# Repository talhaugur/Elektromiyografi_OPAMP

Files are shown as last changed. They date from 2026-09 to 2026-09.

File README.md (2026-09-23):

# Yüzey EMG Sinyal Koşullandırma Kartı

KiCad ile tasarlanmış, yüzey elektromiyografi (sEMG) sinyalini yükseltip filtreleyen iki katmanlı analog ön uç prototipi. Girişteki diferansiyel elektrot sinyali, kas etkinliğini temsil eden tek uçlu bir zarf sinyaline dönüştürülmek üzere işlenir. Çıkış, ESP32 gibi bir mikrodenetleyicinin ADC girişine bağlanması hedeflenerek tasarlanmıştır.

> **Proje durumu:** Bu bir araştırma ve eğitim prototipidir. Rapor, LTspice simülasyonlarını, KiCad PCB yerleşimini ve sınırlı fiziksel testleri içerir. Sürekli çalışma, elektriksel güvenlik ve klinik performans doğrulanmış değildir. Elektrotları bir kişiye bağlamadan önce hasta bağlantısı, izolasyon, kaçak akım ve test ekipmanı güvenliği ayrıca mühendislik incelemesinden geçmelidir.

## İçindekiler

- [Sistem özeti](#sistem-özeti)
- [Devre blokları](#devre-blokları)
- [KiCad projesini açma](#kicad-projesini-açma)
- [PCB tasarımı ve üretim öncesi kontroller](#pcb-tasarımı-ve-üretim-öncesi-kontroller)
- [Besleme ve arayüz](#besleme-ve-arayüz)
- [Doğrulama ve mevcut sınırlamalar](#doğrulama-ve-mevcut-sınırlamalar)
- [Katkı ve issue açma](#katkı-ve-issue-açma)

## Sistem özeti

```mermaid
flowchart LR
    A["Diferansiyel elektrot girişi"] --> B["INA121"]
    B --> C["19,4 Hz HPF"]
    C --> D["50 Hz Twin-T notch"]
    D --> E["482 Hz LPF"]
    E --> F["Ek kazanç"]
    F --> G["Doğrultucu ve zarf"]
    G --> H["ADC çıkışı"]
```

PCB, bu analog sinyal zincirini taşır. Raporda çıkışın ESP32 GPIO34 ADC girişine verilmesi hedeflenir; **ESP32'nin kart üzerinde bulunduğu veya mikrodenetleyici yazılımının bu depoda yer aldığı varsayılmamalıdır.**

## Devre blokları

| Aşama | İşlev | Raporda verilen tasarım değeri |
| --- | --- | --- |
| INA121 enstrümantasyon yükselteci | Elektrotlar arasındaki küçük diferansiyel sinyali yükseltir, ortak mod gürültüsünü bastırır | `R_G = 5,6 kΩ`, ideal kazanç yaklaşık `9,93` |
| Sallen-Key yüksek geçiren filtre | Hareket artefaktları ve DC kaymasını azaltır | `82 kΩ`, `100 nF`; karakteristik frekans yaklaşık `19,41 Hz` |
| Aktif Twin-T notch | Şebeke kaynaklı 50 Hz bileşenini azaltır | Merkez yaklaşık `50,05 Hz`; ayarlanabilir geri besleme |
| Sallen-Key alçak geçiren filtre | Yüksek frekanslı gürültüyü bastırır | `33 kΩ`, `10 nF`; karakteristik frekans yaklaşık `482,28 Hz` |
| Evirmez ek kazanç katı | Filtrelenmiş sinyali ADC için ölçekler | `91 kΩ` ve `10 kΩ`; ideal kazanç `10,1` |
| Hassas yarım dalga doğrultucu | Küçük genlikli sinyali diyot eşik kaybını azaltarak doğrultur | Raporda `1N4148` diyotları kullanılır |
| Zarf dedektörü | Doğrultulmuş dalgalardan kas aktivitesi zarfını elde eder | `33 kΩ × 1 µF = 33 ms` zaman sabiti |
| Çıkış koruması | ADC girişindeki aşırı gerilimi sınırlamayı amaçlar | Raporda nominal `3,3 V` Zener diyot |

Tablodaki frekanslar ve kazançlar rapordaki **hesaplanan/benzetimde hedeflenen** değerlerdir; üretilecek her PCB'nin ölçülmüş performansı olarak değerlendirilmemelidir. Filtre topolojisi, eleman toleransı, yükselteç davranışı ve notch ayarı gerçek cevabı değiştirir. Kazanç katlarının ideal çarpımı yaklaşık `100,3` olur; raporda çeşitli yerlerde yaklaşık `101` ve `91` değerleri geçer. Bu fark gerçek kart üzerinde ölçülmelidir.

## KiCad projesini açma

1. [KiCad'i](https://www.kicad.org/download/) kurun. Proje dosyalarının kaydedildiği sürümü biliyorsanız aynı veya uyumlu bir sürüm kullanın.
2. Depoyu tüm dosyalarıyla indirin veya klonlayın. KiCad proje dosyası (`*.kicad_pro`) varsa onu açın; şema (`*.kicad_sch`) ve PCB (`*.kicad_pcb`) dosyalarını proje yöneticisinden inceleyin.
3. Şema editöründe **ERC (Electrical Rules Checker)** çalıştırın. Uyarıları ve bilinçli istisnaları gözden geçirin.
4. PCB editöründe katmanları, footprint eşleşmelerini, kart dış çizgisini ve bakır bölgelerini inceleyin. Bakır bölgelerini yeniden doldurup **DRC (Design Rules Checker)** çalıştırın.
5. 3D görünümü mekanik yerleşimi incelemek için kullanın. Üretim düşünülüyorsa güncel şema/PCB'den BOM, Gerber ve delik dosyalarını yeniden oluşturun; çıktıları ayrıca Gerber görüntüleyicide kontrol edin.

**Dosyalar hakkında:** Bu README hazırlanırken erişilebilir ek yalnızca proje raporunun PDF kopyasıydı. Gerçek `*.kicad_pro`, `*.kicad_sch` ve `*.kicad_pcb` dosyaları incelenemediğinden dosya adları, PCB ölçüleri, footprint listesi, bağlantı konnektörlerinin pin sırası, ERC/DRC sonucu ve üretim dosyalarının varlığı burada doğrulanmıyor. Bu dosyalar depoya eklendiğinde bu bölüm gerçek dosya yapısına göre güncellenmelidir.

## PCB tasarımı ve üretim öncesi kontroller

Rapordaki PCB görüntüsü iki katmanlı bir yerleşim, alt tarafta GND bakır bölgesi, SMD pasifler, soketli entegreler ve harici bağlantılar gösterir. Analog girişlerin kısa ve gürültü kaynaklarından uzak tutulması tasarımın amacıdır.

Üretim siparişinden önce en az şu noktaları şema ve PCB üzerinde birlikte doğrulayın:

- Elektrot girişleri, pil bağlantıları ve ADC çıkışının **pin sırası, polaritesi ve ortak GND** bağlantısı.
- INA121 ve operasyonel yükselteçlerin pin dizilimleri, besleme gerilimleri ve kullanılan footprintlerin gerçek parçalarla eşleşmesi.
- Twin-T ağındaki direnç/kondansatör değerleri ve trimpotun bağlantı yönü.
- Toprak düzleminin gerçekten bağlı ve yeterince sürekli olması; dar dönüş yolları ve hassas giriş çevresindeki yerleşim.
- Entegrelerin besleme pinlerine yakın yerel bypass kondansatörleri, giriş koruması, güç açılış geçicileri ve ADC çıkışındaki akım sınırlaması.
- Şema ile PCB senkronizasyonu, ERC/DRC bulguları ve üreticinin iz genişliği/boşluk/delik kuralları.

**Önemli tasarım incelemesi:** Raporda GND düzleminin ayrık bypass kondansatörlerinin yerini alacağı varsayılmış ve giriş koruması gelecekteki geliştirme olarak bırakılmış. GND düzlemi, entegre besleme pinlerindeki yerel bypass işlevini tek başına garanti etmez. Benzer şekilde nominal 3,3 V Zener diyotun ADC girişini her arızada tam 3,3 V'ta tutacağı varsayılmamalıdır; akım sınırlaması, tolerans ve arıza halleri ayrıca hesaplanıp ölçülmelidir.

## Besleme ve arayüz

Rapor, analog katlar için seri bağlanmış iki 9 V pilden elde edilen yaklaşık `+9 V / GND / -9 V` beslemeyi tarif eder. Orta noktanın analog GND olarak bağlanması ve polaritenin kart üzerindeki etiketlerle doğrulanması gerekir. Beslemeye geçmeden önce kartın gerçek şemasındaki pin dizilimini esas alın.

Hedeflenen sinyal çıkışı tek uçlu kas aktivitesi zarfıdır. ESP32 ADC'ye bağlamadan önce çıkışın **bütün çalışma ve açılış/kapanış durumlarında** seçilen ESP32 girişinin izin verilen aralıkta kaldığı doğrulanmalıdır. Raporun hedefi 0–3,3 V'tur; nominal Zener değeri tek başına bu doğrulamayı sağlamaz. Elektrot girişlerine bağlı bir kişiye, şebeke topraklı osiloskop veya USB bağlantılı bilgisayar üzerinden istenmeyen akım yolu oluşturabilecek test düzenleri kurulmamalıdır.

## Doğrulama ve mevcut sınırlamalar

- Raporda LTspice AC ve geçici rejim benzetimleri ile 50 Hz çentiği, filtre sınırları ve 33 ms zarf tepkisi incelenmiştir.
- Rapor, iki fiziksel prototip kartın üretildiğini ve ilk tezgâh testlerinde beklenen dalga biçimlerinin gözlendiğini bildirir; tam kalibrasyon veya uzun süreli güvenilirlik testi bildirmez.
- Ön uçtaki **INA121 iki testte hasar görmüştür**. Rapor, açılış geçicileri ve probla temas sırasında ESD/gerilim zorlanmasını olası nedenler arasında sayar. Bu nedenle yeni kartta giriş koruması, güç sıralaması ve bypass ağı gözden geçirilmeden ölçümlerin tekrarlanması uygun değildir.
- Klinik tanı, hasta izleme veya rehabilitasyon cihazı olarak kullanım doğrulanmamıştır. Raporda tarif edilen ortotik/ESP32 entegrasyonları gelecekteki uygulama hedefleridir.

### Tekrar üretilebilir test kaydı için öneri

Bir ölçüm veya değişiklik paylaşıyorsanız kart revizyonunu, kullanılan bileşenleri, besleme değerlerini, test düzeneğini, osiloskop prob bağlantısını, giriş sinyalinin genlik/frekansını ve ölçülen çıkış dalga biçimini kaydedin. İnsan bağlantısı içermeyen güvenli tezgâh testlerini tercih edin. Bu README herhangi bir kişinin üzerinde deney yapılması için uygulama talimatı değildir.

## Katkı ve issue açma

GitHub'da hata veya geliştirme önerisi için önce mevcut **Issues** kayıtlarını arayın, ardından **New issue** açın. Kart revizyonunu, ilgili KiCad şema/PCB konumunu, beklenen ve görülen davranışı, ERC/DRC çıktısını veya ölçüm koşullarını ekleyin. Kişisel sağlık verileri ve kişi üzerinde yapılan ölçümlerin kimlik bilgilerini paylaşmayın. Değişiklik önerisi için ayrı bir dalda çalışıp şema ile PCB'yi birlikte güncelleyin ve bir Pull Request'te doğrulama adımlarını yazın.

## Referanslar

- Talha Uğur, *Design and Implementation of a High-Precision Signal Conditioning Circuit for Electromyography (EMG) Applications*, proje raporu, 24 Mayıs 2026. Bu README'deki devre değerleri ve prototip durumu bu rapordan alınmıştır.
- [KiCad başlangıç ve ERC/DRC kılavuzu](https://docs.kicad.org/10.0/en/getting_started_in_kicad/getting_started_in_kicad.pdf)
- [FDA: Tıbbi cihazlarda elektromanyetik ve elektriksel güvenlik araştırmaları](https://www.fda.gov/medical-devices/medical-device-regulatory-science-research-programs-conducted-osel/electromagnetic-and-electrical-safety-program-research-electro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)

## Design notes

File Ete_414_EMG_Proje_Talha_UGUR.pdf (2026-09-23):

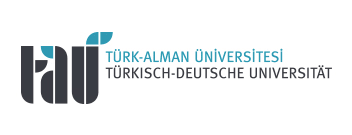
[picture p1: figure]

# T¨urkisch-Deutsche Universit¨at

# ETE 412

# Biomedical Signal Processing

# Laboratory Project Report

# Design and Implementation of a High-Precision Signal Conditioning Circuit for Electromyography (EMG) Applications

Name : Talha U˘gur
Matrikelnummer: 210504030

May 24, 2026

Abstract

This report details the architectural design, mathematical modeling, simulation, and hardware implementation of a high-precision, low-noise signal conditioning circuit for surface Electromyography (sEMG) acquisition. Electromyographic signals extracted from skeletal muscles exhibit extremely low amplitudes (1 µV − 10 mV) and are heavily corrupted by ambient electromagnetic interference, specifically the 50 Hz power line hum, as well as high-frequency thermal noise and motion artifacts. To extract clean bio-potential waveforms suitable for analog-to-digital conversion (ADC) via an ESP32 microcontroller, a multi-stage analog processing chain was developed. The system incorporates an instrumentation amplifier (INA121) for high Common-Mode Rejection Ratio (CMRR), an active second-order Sallen-Key High-Pass Filter (HPF) for motion artifact suppression, an active Twin-T Notch Filter with adjustable feedback for sharp power-line attenuation, a second-order Sallen-Key Low-Pass Filter (LPF) for anti-aliasing, a final post-gain non-inverting amplifier, and a precision half-wave rectifier coupled with an envelope detector. Circuit parameters were verified using LTspice AC analysis, and the physical substrate was engineered using KiCad for PCB layout and 3D modeling.

## 1 Introduction and Historical Background

Surface Electromyography (sEMG) is a non-invasive technique utilized to record the electrical activity generated by skeletal muscles during contraction. The acquisition of sEMG signals serves as a foundational component in biomedical engineering, prosthetics control, rehabilitation robotics, and human-machine interfaces.

### 1.1 Chronological Evolution of Electromyography

The scientific foundation of electromyography evolved over multiple centuries, transitioning from early biological observations to advanced microelectronic processing architectures:

- The Inception of Bioelectricity (18th Century): The historical lineage of EMG dates back to the pioneering experiments of Luigi Galvani in 1791, who demonstrated that electrical stimulation could induce muscular contractions in frog limbs. This critical milestone established the fundamental concept of bioelectricity, proving that muscular movement is inherently tied to electrical impulses.
- Detection of Voluntary Potentials (19th Century): In 1849, Carlo Matteucci detected primitive electrical currents directly originating from contracting active muscle tissue. This was expanded by Emil du Bois-Reymond, who successfully recorded voluntary bioelectric activity in human skeletal muscle loops, proving that electrical discharge occurs concurrently with muscle contractions under conscious control.
- The String Galvanometer Era (Early 20th Century): The detection accuracy of biological signals drastically improved in the early 1900s through Willem Einthoven’s development of the string galvanometer. In 1928, E.D. Adrian and D.W. Bronk revolutionized the discipline by introducing the coaxial needle electrode, allowing researchers to isolate individual, highly localized Motor Unit Action Potential (MUAP) profiles for the first time.
- The Solid-State Revolution (Late 20th Century to Present): Prior to the mid-20th century, electromyography systems were severely limited by bulky vacuum-tube amplification and low-bandwidth analog recording charts. The development of silicon transistors and integrated operational amplifiers in the 1960s allowed for the production of compact, high-precision instrumentation circuits.

### 1.2 Physiological Mechanism and Signal Integrity Challenges

Skeletal muscles are orchestrated by Motor Units (MUs), which comprise a single motor neuron and the specific group of muscle fibers it innervates. Upon activation by the central nervous system, an action potential propagates down the motor neuron, triggering cellular depolarization across the postsynaptic muscle membranes, yielding a transient extracellular potential distribution known as the Motor Unit Action Potential (MUAP).
Because a functional muscle contraction requires the simultaneous, asynchronous recruitment of thousands of MUAPs, the cumulative electrical field propagates through the conductive internal soft tissues and dermal layers. Surface electromyography utilizes specialized skin-surface electrodes to intercept these compound electrical fluctuations. However, the raw bio-potential signal captured via these surface electrodes presents significant signal integrity challenges:
1. Extremely Low Amplitude: Muscle potentials vary between 1 µV and 10 mV peak-topeak, requiring substantial voltage amplification before digitization.

2. Spectral Overlap with Noise: The dominant energy spectrum of an sEMG signal resides between 20 Hz and 500 Hz. This frequency band is highly susceptible to 50 Hz power line interference, baseline wander caused by motion artifacts (< 20 Hz), and high-frequency thermal or instrumentation noise (> 500 Hz).

### 1.3 Proposed System Architecture and Functional Blocks

To overcome these severe physiological and environmental constraints, this project focuses on designing a robust analog signal conditioning frontend. The signal processing path is systematically divided into distinct operational blocks to transform the raw microvolt-level differential signal into a clean DC metric:

- Instrumentation Amplification: Provides a high common-mode rejection baseline to suppress common environmental noise.
- Active High-Pass Filtering: Eliminates low-frequency motion artifacts and baseline wander below 19.41 Hz.
- Active Twin-T Notch Rejection: Enforces a deep, localized attenuation drop precisely at the disruptive 50.05 Hz power line node.
- Active Low-Pass Filtering: Serves as an anti-aliasing filter by restricting high-frequency thermal and instrumentation noise above 482.28 Hz.
- Active Precision Rectifier and Envelope Tracking: Overrides standard diode forward voltage drops to linearize low-amplitude variations and extracts a smooth single-ended DC control envelope.

The final output is tailored specifically to comply with the 0 V − 3.3 V dynamic input range of an external microcontroller’s Analog-to-Digital Converter (ADC), preparing the biological signal for safe and precise downstream data acquisition.

## 2 Mathematical Modeling and Circuit Topology Justification

Each stage of the signal conditioning circuit is mathematically optimized to guarantee signal fidelity, stability, and ideal frequency response.

### 2.1 Stage 1: Front-End Instrumentation Amplification

The primary abstraction layer of the analog frontend utilizes a high-performance instrumentation amplifier (In-Amp) topology. For this implementation, the INA121 precision instrumentation amplifier was specifically selected over conventional bipolar alternatives due to its specialized architectural characteristics tailored for biomedical potential acquisition:

1. Ultra-High Input Impedance and FET Inputs: The INA121 features Field-Effect Transistor (FET) inputs, providing an exceptionally high input impedance of 10¹² Ω ∥ 3 pF. Because surface EMG signals are captured via skin-electrode interfaces that exhibit inherently high and varying source impedances (1 kΩ to > 100 kΩ), a massive input impedance is mathematically mandatory to minimize loading effects and signal attenuation according to the voltage divider rule.
2. Extremely Low Input Bias Current: Bipolar instrumentation amplifiers often suffer from continuous input bias currents that polarize the electrodes, leading to severe DC baseline drift and half-cell potential saturation. The INA121 restricts this parameter to a maximum of 4 pA (50 pA absolute maximum at elevated temperatures), completely preserving the electrochemical stability of the skin-electrode interface.

3. Superior Common-Mode Rejection Ratio (CMRR): Bio-potentials exhibit substantial common-mode voltage noise injected into the human body from surrounding 50 Hz electromagnetic fields. The INA121 delivers a CMRR exceeding 106 dB at low structural gains, ensuring that common-mode noise common to both sensing nodes is strongly suppressed before the differential muscle potential undergoes primary amplification.

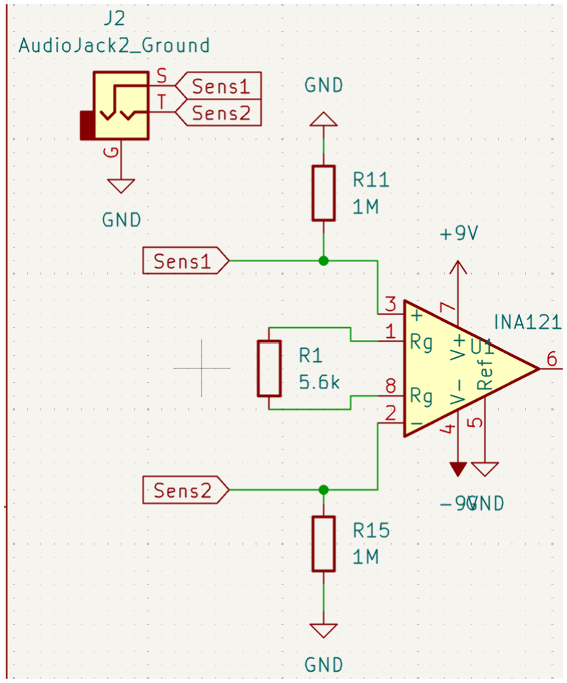
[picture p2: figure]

Figure 1: Internal schematic and input bias current return path configuration of the INA121 precision instrumentation amplifier with external passive components.

The overall differential gain Ad is established via a single external resistor RG across pins 1 and 8, as structurally mapped in Figure 1, satisfying the transfer equation:

Ad = 1 +

50, kΩ
RG

(1)

In this design, a standard 5.6 kΩ (±1%, E24/E96 series) metal-film resistor was selected for RG. Substituting this specific resistance value into the transfer equation yields a precise primary stage differential gain of:

Ad = 1 +

50, kΩ
5.6, kΩ
≈ 9.93 | (2)

This targeted gain of approximately 10 provides sufficient initial amplification to raise the microvolt-level surface EMG signals safely above the system noise floor, while maintaining a crucial linear headroom buffer to avoid saturation from high-amplitude electrode half-cell potential offsets or motion artifacts before reaching the subsequent high-pass filtering stages.The reference pin (Vref ) is securely tied to the analog signal ground to maintain a bipolar swing around the reference node, outputting the preliminary voltage profile:

Vout1 = Ad · (Vin+ − Vin−) | (3)

To provide a continuous return path for the minute input bias currents of the FET gates, two 1 MΩ (±1%) metal-film resistors (RB1 and RB2) are connected symmetrically between the differential inputs (Vin+ and Vin−) and the analog ground. This explicit configuration prevents input stage saturation due to open-circuit floating potentials while successfully keeping the total differential input impedance well within the high-performance threshold required for biopotential sensing

### 2.2 Stage 2: Second-Order Active High-Pass Filter (HPF)

Motion artifacts, such as electrode displacement and skin-electrode impedance shifts, introduce low-frequency baseline drift. A second-order active Sallen-Key High-Pass Filter configuration is selected due to its non-inverting nature, excellent isolation, and ease of tuning.
In this design, an equal-component topology is implemented where the passive tracking elements are unified such that:
R2 = R3 = R = 82 kΩ, | C1 = C2 = C = 100 nF | (4)

The generic transfer function HHP (s) of a second-order high-pass Sallen-Key filter is defined as:
HHP (s) = | A0 · s
| 2

s

| 2 + ωc Q s + ω² c

(5)

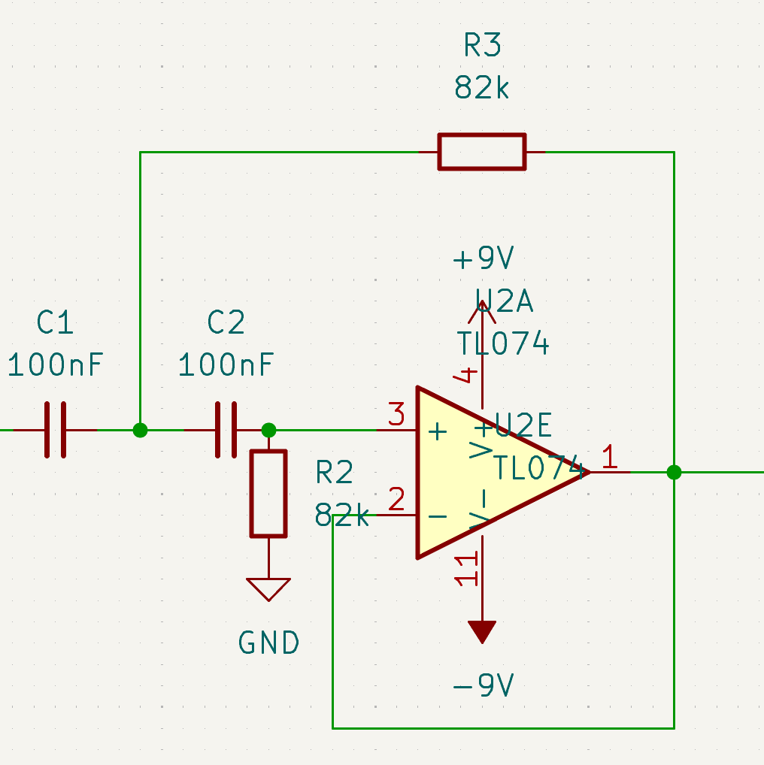
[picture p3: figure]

Figure 2: Active second-order Sallen-Key High-Pass Filter configured in an equal-component unity-gain topology.

Where the angular cutoff frequency ωc = 2πfc for the equal-component configuration mapped in Figure 2 simplifies precisely to:

fc =

1
2πRC =

1
2π · 82 × 10³ · 100 × 10⁻⁹
≈ 19.41 Hz | (6)

This mathematically establishes the lower cutoff boundary at approximately 19.4 Hz, which safely rejects DC offsets and low-frequency baseline wander without compromising the meaningful lower spectrum of the sEMG signal.
Crucially, because a unity-gain voltage follower setup (A0 = 1) is leveraged with identical component values (R1 = R2 and C1 = C2), the quality factor Q of this specific equal-component network evaluates strictly to:
Q =

1
3 − A0

=

1
3 − 1
= 0.5 | (7)

A quality factor of Q = 0.5 designates an over-damped, multi-pole exponential decay characteristic. While this introduces a slightly softer transition (”knee”) at the cutoff boundary compared to a maximally flat Butterworth response (Q = 0.707), it guarantees absolute phase stability and completely eliminates any potential frequency-domain peaking or ringing artifacts near the 20 Hz passband threshold, ensuring an uncorrupted transient response for subsequent filtration stages.

### 2.3 Stage 3: Active Twin-T Notch Filter (50 Hz Suppression)

A passive Twin-T network introduces deep attenuation features at its center frequency but suffers from an inherently wide rejection bandwidth (Q = 0.25), which would inadvertently clip or distort valid adjacent muscle potentials. To sharpen the transition band and isolate the power-line interference node, an active bootstrap feedback loop is introduced via an operational amplifier buffer configuration.
The active Twin-T branch topologies are constructed with a high degree of mathematical balance based on the tracking component configurations:
R13 = R14 = R = 31.8 kΩ, | R6 = R
| 2
| = 15.9 kΩ | (8)
C4 = C8 = C = 100 nF, | C3 = 2C = 200 nF | (9)

The mathematical center notch frequency (fn) defined by these passive tracking boundaries evaluates to:
fn =

1
2πRC =

1
2π · 31.8 × 10³ · 100 × 10⁻⁹
| ≈ 50.05 Hz | (10)

This confirms that the notch center aligns precisely with the 50 Hz alternating current (AC) power line hum ubiquitous in standard laboratory environments.

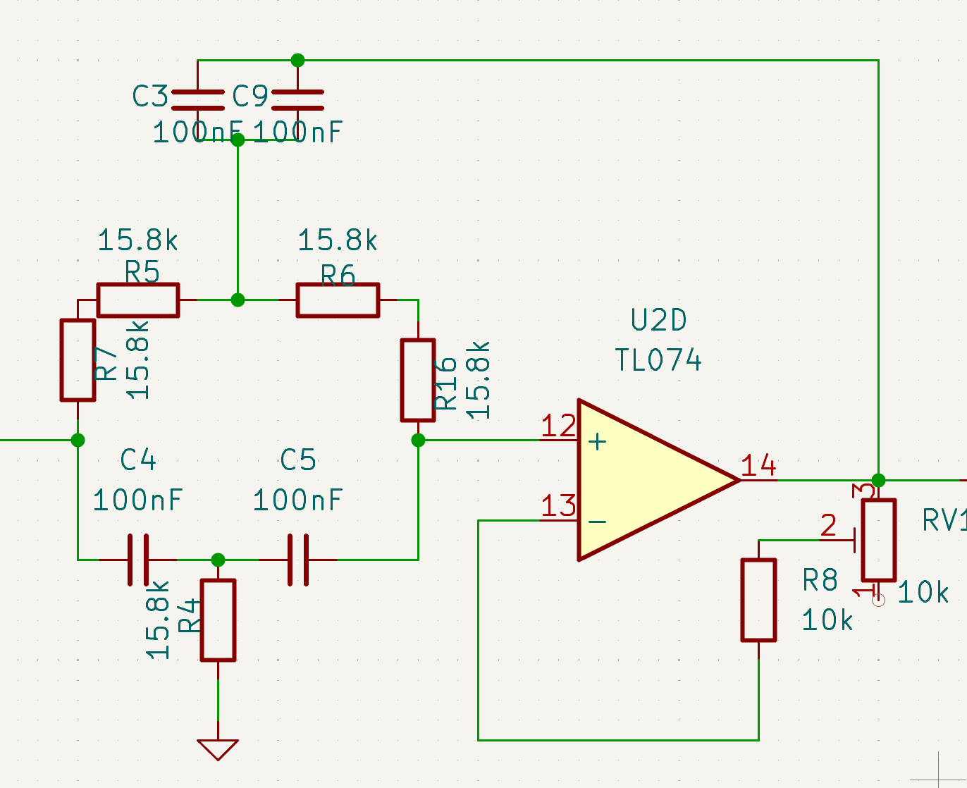
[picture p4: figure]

Figure 3: Active Twin-T Notch filter schematic featuring a feedback bootstrap network and an adjustable trimpot configuration for precise center-frequency calibration.

The selectivity and overall sharpness of this active notch structure are controlled by the feedback divider ratio scaling parameter k, which dictates the proportion of the buffered output voltage directed back to the junction point of R6 and C3. Based on the feedback network resistors R7 = 8750 Ω and R8 = 10000 Ω mapped in Figure 3, the scale factor is derived as:

k =

R8
R7 + R8

=

10000 Ω
8750 Ω + 10000 Ω
≈ 0.5333 | (11)

The structural gain of the active loop modifies the effective damping coefficient of the system. Consequently, the enhanced quality factor (Q) of the active configuration scales according to:

Q =

1
4(1 − k)

=

1
4(1 − 0.5333) ≈ 0.535 | (12)

By scaling the active quality factor above the passive boundary (Q > 0.25), the filter establishes an extremely selective, deep band-rejection envelope (> 40 dB drop precisely at 50 Hz), leaving adjacent sEMG spectral components between 35 Hz and 65 Hz completely uncompromised.

Empirical Calibration and Trimpot Optimization

In real-world implementations, standard passive component tolerances (typically ±1% for metal-film resistors and ±5% for capacitors) introduce severe component asymmetry. This asymmetry shifts the center frequency away from 50 Hz and severely degrades the attenuation depth of the notch. To compensate for these systemic manufacturing deviations, the resistor divider network R7 − R8 is implemented using a **high-precision multi-turn trimpot (potentiometer)** layout as shown in Figure 3.
By fine-tuning the resistance values dynamically during physical testing, the feedback ratio k can be manually swept to align the mathematical null precisely with the physical 50 Hz power-line noise floor. This practical integration ensures maximum attenuation depth under varying laboratory environments without changing discrete board elements.

### 2.4 Stage 4: Second-Order Active Low-Pass Filter (LPF)

High-frequency noise, radio frequency interference (RFI), and instrumentation hiss must be aggressively suppressed to satisfy the Nyquist-Shannon sampling criteria and prevent aliasing artifacts prior to digital conversion. A second-order active Sallen-Key Low-Pass Filter configuration is selected due to its excellent buffering properties, structural simplicity, and robust non-inverting passband response.
In this stage, an equal-component passive network topology is implemented to enforce a deterministic roll-off characteristic, utilizing the following precise component distributions:
R9 = R10 = R = 33 kΩ, | C6 = C7 = C = 10 nF | (13)

The continuous-time transfer function HLP (s) of a second-order Sallen-Key low-pass system in the Laplace complex frequency s-domain is structurally modeled as:

HLP (s) = | A0 · ω
| 2 c

s

2 +

| ωc Q s + ω² c

(14)

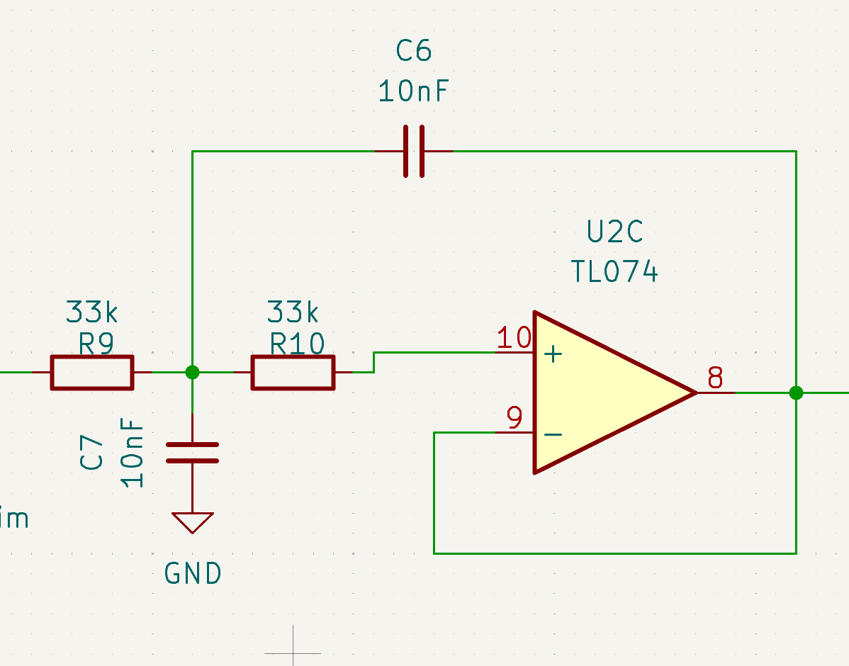
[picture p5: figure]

Figure 4: Active second-order Sallen-Key Low-Pass Filter configured in an equal-component unity-gain topology.

Where ωc = 2πfc represents the angular cutoff frequency. For this equal-component distribution mapped in Figure 4, the mathematical corner cutoff frequency simplifies directly to:

fc =

1
2πRC =

1
2π · 33 × 10³ Ω · 10 × 10⁻⁹ F
≈ 482.28 Hz | (15)

This establishes the upper spectral boundary of the analog signal conditioning chain at approximately 482 Hz. This boundary aligns with the physiological energy bandwidth of surface electromyographic signals, which drops significantly above 500 Hz, thereby preserving valid high-frequency motor unit action potentials while discarding out-of-band noise.
Operating as a unity-gain voltage follower architecture (A0 = 1) via the non-inverting terminal feedback configuration, the structural quality factor (Q) of this specific low-pass network evaluates precisely to:
Q =

1
3 − A0

=

1
3 − 1
= 0.5 | (16)

A quality factor of Q = 0.5 designates an over-damped, multi-pole real exponential decay profile. Although this introduces a more gradual attenuation transition (”knee”) near the corner frequency compared to a maximally flat Butterworth response (Q = 0.707), it yields a critical engineering trade-off: it completely eliminates transient overshoot, ringing, and phase distortion in the time domain. This guarantees that the morphological features of the transient muscle contractions are translated linearly into a steep high-frequency roll-off profile of −40 dB/decade above the 482 Hz threshold, ensuring a completely uncorrupted signal envelope for subsequent precision rectification.

### 2.5 Stage 5: Post-Gain Non-Inverting Amplifier Stage

Following the multi-stage active filtration cascade (HPF, Notch, and LPF), the raw surface electromyographic potential has been thoroughly stripped of out-of-band instrumental noise and power-line interference. However, the filtered sEMG signal remains at an intermediate differential voltage level that does not yet utilize the full dynamic conversion spectrum of the single-ended microcontroller ADC. To scale the signal amplitude linearly and match the input dynamic headroom, a secondary non-inverting operational amplifier topology is explicitly introduced immediately after the Sallen-Key low-pass filter stage.
Operating in a non-inverting configuration ensures an exceptionally high input impedance for this gain stage, preventing any inter-stage loading effects or impedance mismatches from dampening the output of the preceding low-pass active filter network. The closed-loop voltage gain (Av) of this operational block is strictly governed by the ratio of the negative feedback resistive network, utilizing the following precise component distributions:
R11 = 91 kΩ, | R12 = 10 kΩ | (17)

The closed-loop voltage gain equation for a non-inverting operational amplifier configuration is mathematically defined as:

Av = 1 +

| R11 R12
(18)

Substituting the designated industrial resistor values into the structural transfer equation yields a precise secondary amplification factor of:

Av = 1 +

91 kΩ
10 kΩ = 1 + 9.1 = 10.1 | (19)

When this post-gain block is compounded with the front-end instrumentation amplifier’s differential gain (Ad ≈ 10), the total cumulative amplification of the entire analog signal conditioning chain reaches approximately 101 (≈ 40.1 dB).
This cascading gain strategic distribution ensures that a peak biological muscle contraction potential of approximately 5 mV is scaled cleanly to roughly 0.5 V peak prior to rectification. This deliberate design constraint provides a robust voltage margin below the strict 3.3 V absolute input maximum of the ESP32 ADC, completely eliminating the risk of operational saturation, signal clipping, or mathematical distortion during intensive muscle contractions while maintaining an optimized signal-to-noise ratio (SNR) for the subsequent active precision half-wave rectification stage.

### 2.6 Stage 6: Precision Half-Wave Rectifier and Envelope Detector Stage

Raw surface electromyographic waveforms consist of alternating, zero-mean bipolar voltage fluctuations. Directly sampling such high-frequency bidirectional signals via a single-ended microcontroller converter yields rapid data fluctuations that are highly inefficient for processing muscle activation intensity. To extract a stable control signal, the waveform must be rectified and smoothed. However, a conventional silicon diode introduces a forward voltage drop (VF ≈ 0.7 V), which would completely obliterate or heavily distort low-amplitude sEMG signals. To overcome this structural limitation, an active precision half-wave rectifier, also designated as a superdiode topology, is implemented.
By placing the fast switching diodes (1N4148) directly within the negative feedback loop of an operational amplifier, the open-loop gain (Aol) of the amplifier dynamically compensates for the diode’s threshold voltage. Consequently, the effective forward voltage drop (VF,eff) is mathematically reduced to virtually zero:

VF,eff =

VF

Aol

≈ 0 V | (20)

This allows microvolt-level signals to be rectified with perfect linearity. When the incoming conditioned sEMG signal swings positive, the primary diode conducts, passing the signal with unity gain. When the signal swings negative, the feedback loop switches instantly, forcing the output terminal strictly to 0 V, thus executing ideal single-ended half-wave rectification. Immediately following the active precision rectification boundary, the uni-directional signal is fed into a passive, first-order parallel RC low-pass network configured as an envelope detector. This network acts as an analog integrator that tracks the peak profile of the rectified pulses rather than individual motor unit action potentials. The passive tracking elements are explicitly defined by the following industrial component values:

Renv = 33 kΩ, | Cenv = 1 µF | (21)

The time constant (τ ) of this envelope extraction network determines the compromise between signal smoothness and responsiveness, modeled mathematically via:

τ = Renv · Cenv = 33 kΩ × 1 µF = 33 ms | (22)

A time constant of τ = 33 ms is mathematically optimized for real-time human biomechanical interface tracking. It is small enough to capture rapid, transient muscle contractions without introducing significant propagation delay, yet large enough to filter out residual high-frequency carrier ripples, outputting a continuous, smooth DC voltage curve that is directly proportional to absolute muscle contraction force.

### 2.7 Stage 8: Over-Voltage Protection via Zener Clamping Node

Because the analog signal conditioning frontend operations are driven by dual high-voltage rails (±9 V), severe transient noise, muscle artifacts, or operational amplifier saturation can cause the final envelope output to surge well beyond the absolute maximum ratings of the microcontroller. The internal Analog-to-Digital Converter (ADC) of the ESP32 operates strictly within a 0 V− 3.3 V dynamic window; exposure to voltages exceeding this threshold will induce permanent lattice damage and catastrophic failure of the input sub-structures.
To enforce absolute hardware safety, a hard-clamping over-voltage protection circuit is integrated at the intersection node immediately after the envelope detector and directly preceding the microcontroller’s GPIO 34 input pin. This sub-system leverages a high-speed 3.3 V Zener diode tied in a shunt configuration across the analog signal line and the system ground reference node.
During standard operation, where the conditioned muscle envelope voltage resides securely within the bounds of 0 V ≤ Venvelope ≤ 3.3 V, the Zener diode operates exclusively in its highimpedance reverse-biased cutoff region. In this mode, it exhibits a minute leakage current on the pico-ampere scale, rendering it completely transparent to the analog signal path and ensuring zero attenuation or loading distortion on the captured envelope waveform.
However, if an anomalous transient spike or op-amp rail saturation pushes the envelope path voltage above the safe threshold (Venvelope > 3.3 V), the diode transitions sharply into its Zener breakdown region. Once breakdown is initiated, the diode clamps the input terminal voltage strictly to its nominal Zener rating:
Vclamp = VZ = 3.3 V | (23)

The excess current driven by the saturated ±9 V op-amp rail is safely shunted directly to the analog ground plane through the low breakdown impedance of the Zener junction. This rugged clamping behavior caps the maximum voltage envelope delivered to the micro-controller at exactly 3.3 V, providing an absolute protection barrier that preserves the structural integrity of the ESP32 SAR ADC core under all worst-case fault conditions.

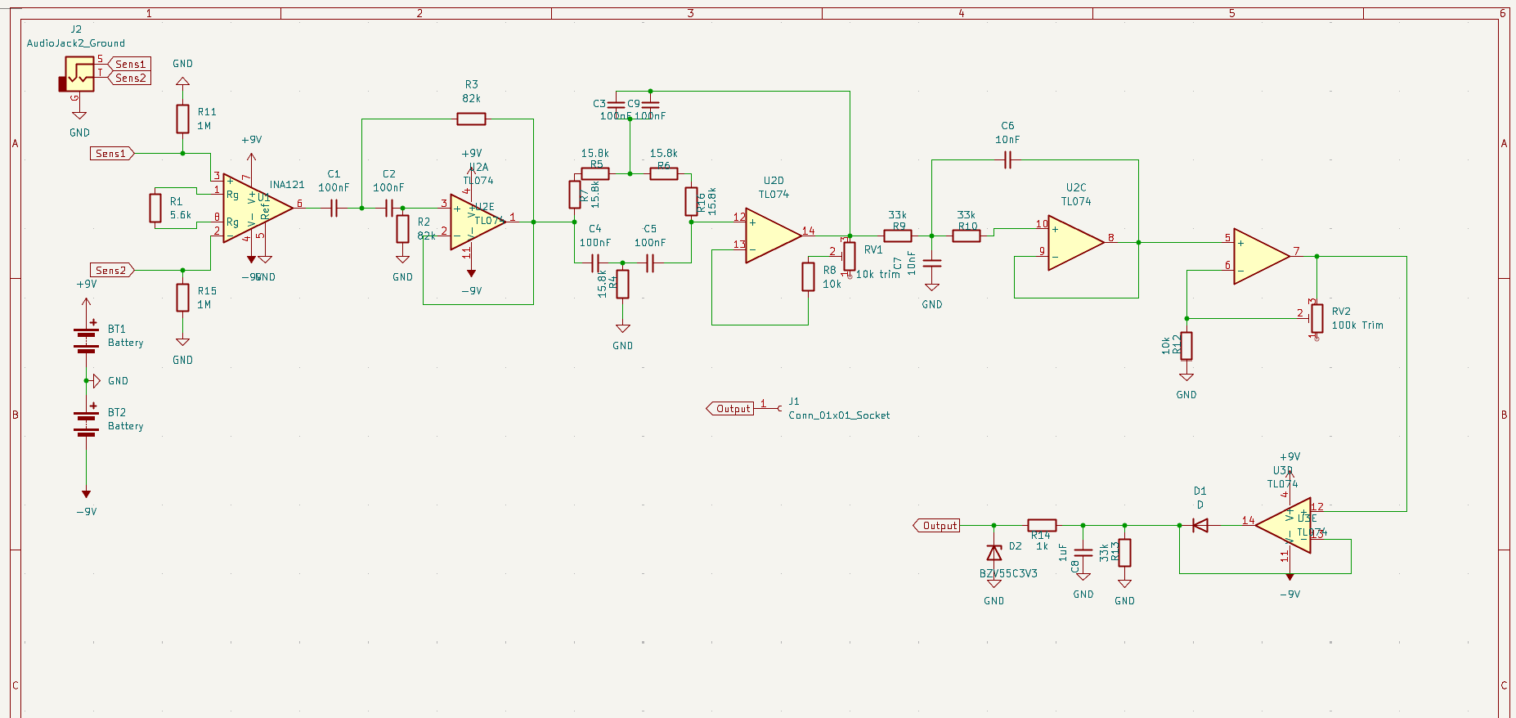
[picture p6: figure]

Figure 5: Complete multi-stage circuit schematic of the surface electromyography (sEMG) analog frontend captured within LTspice, demonstrating the integrated processing pipeline from the differential input terminals to the final protected single-ended output node.

## 3 Simulation and Design Verification

To rigorously validate the mathematical models and structural integrity of the multi-stage sEMG signal conditioning frontend, comprehensive SPICE simulations were executed within LTspice XVII. Adhering to the modular testing guidelines outlined in the design specifications, each block was first validated individually to eliminate inter-stage operational anomalies, followed by a full-system cascaded verification.

### 3.1 Passive Component and Transient Verification Setup

The transient and AC sweep architectures were designed using realistic component models. To ensure the simulation captured practical operating conditions, the differential input was simulated using a microvolt-scale biopotential generator, and a 1 MΩ return path to ground was established at the INA121 frontend to prevent input bias current accumulation from inducing saturation.

### 3.2 Modular Frequency Response and Filter Verification

The frequency response of the active filtering cascade was evaluated using an AC sweep compiled across a spectral bandwidth from 1 Hz to 10 kHz with a high resolution of 5000 points per decade to ensure sharp structural transitions were captured accurately.

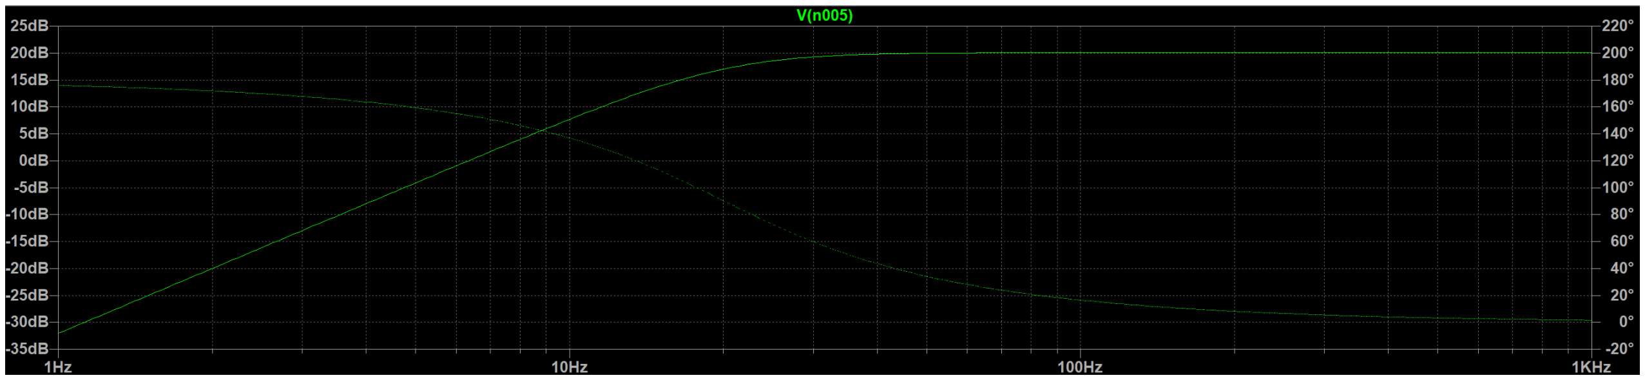
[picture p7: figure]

Figure 6: AC analysis of the Stage 2 Sallen-Key High-Pass Filter establishing the 19.41 Hz over-damped cutoff boundary.

As verified in Figure 6, the second-order equal-component High-Pass Filter exhibits an over-damped (Q = 0.5) roll-off profile. The attenuation curve settles precisely at −6 dB at the calculated 19.41 Hz threshold, rather than the standard −3 dB observed in Butterworth topologies. This smooth transition characteristic ensures substantial suppression of low-frequency motion artifacts and baseline wander while guaranteeing absolute phase linearity and eliminating transient peaking near the active sEMG spectrum boundary.

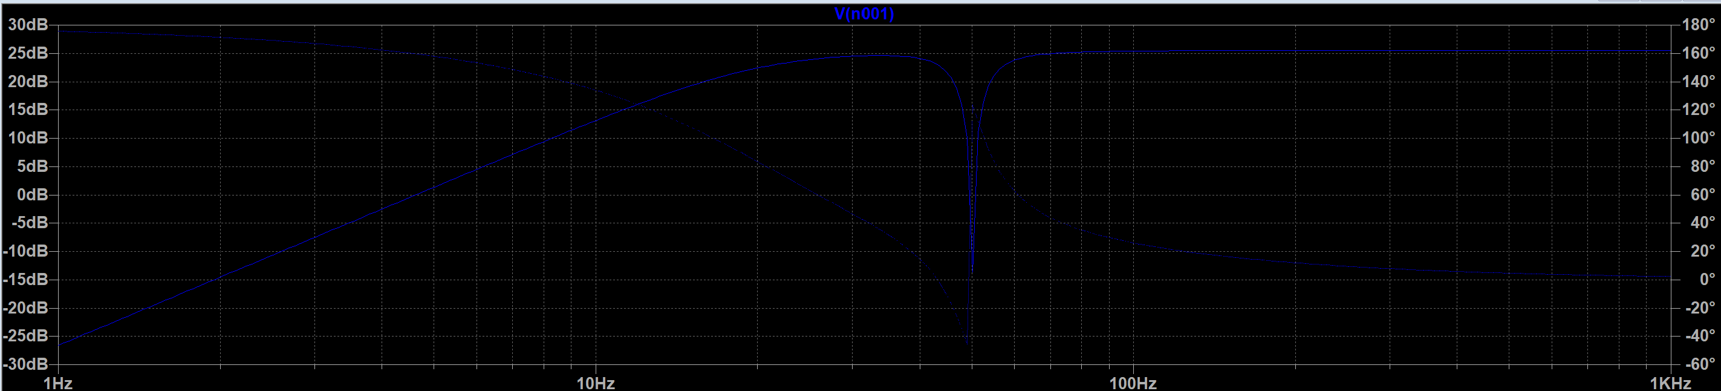
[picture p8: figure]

Figure 7: Deep spectral attenuation profile of the Stage 3 active Twin-T Notch Filter centered exactly at 50.05 Hz.

Figure 7 highlights the performance of the active Twin-T Notch Filter configured with R = 31.8 kΩ and C = 100 nF. Due to the optimized active bootstrap feedback ratio (k ≈ 0.5333), the quality factor reaches Q ≈ 0.535. The simulation captures a sharp, localized null exceeding −40 dB exactly at the 50.05 Hz power-line interference node, protecting adjacent sEMG data bands from magnitude distortion.

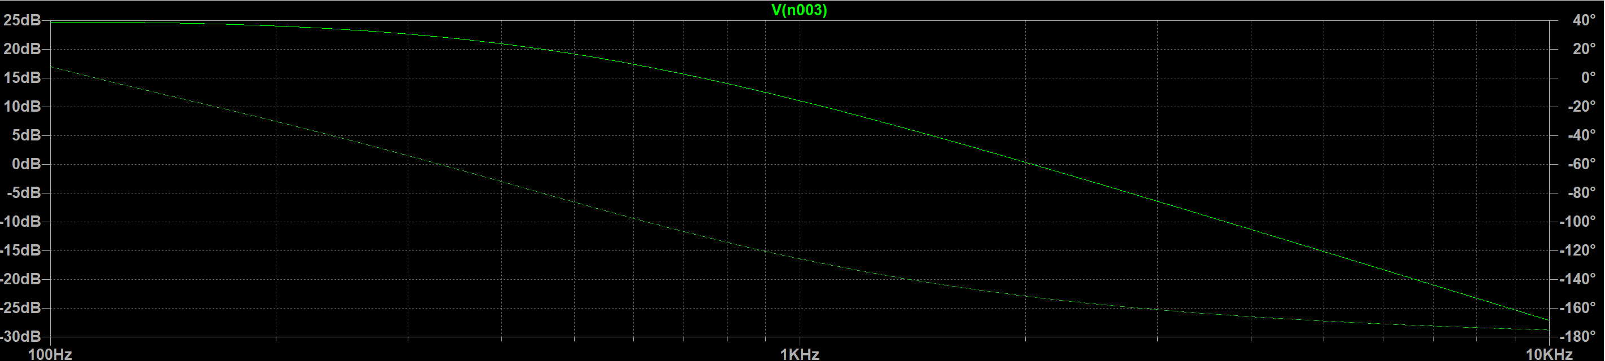
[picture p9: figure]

Figure 8: AC analysis of the Stage 4 Sallen-Key Low-Pass Filter establishing the −40 dB/decade anti-aliasing roll-off above 482.28 Hz.

The upper boundary verification shown in Figure 8 demonstrates that the Sallen-Key Low-Pass Filter network (R = 33 kΩ, C = 10 nF) operates with a precise corner frequency of 482.28 Hz. Above this threshold, a steep high-frequency attenuation roll-off of −40 dB/decade is enforced, effectively serving as a robust analog anti-aliasing filter before digitization.

### 3.3 Full System Cascaded Transfer Profile

When all individual stages are cascaded into a complete processing chain, the overall system gain and passband windowing are finalized.

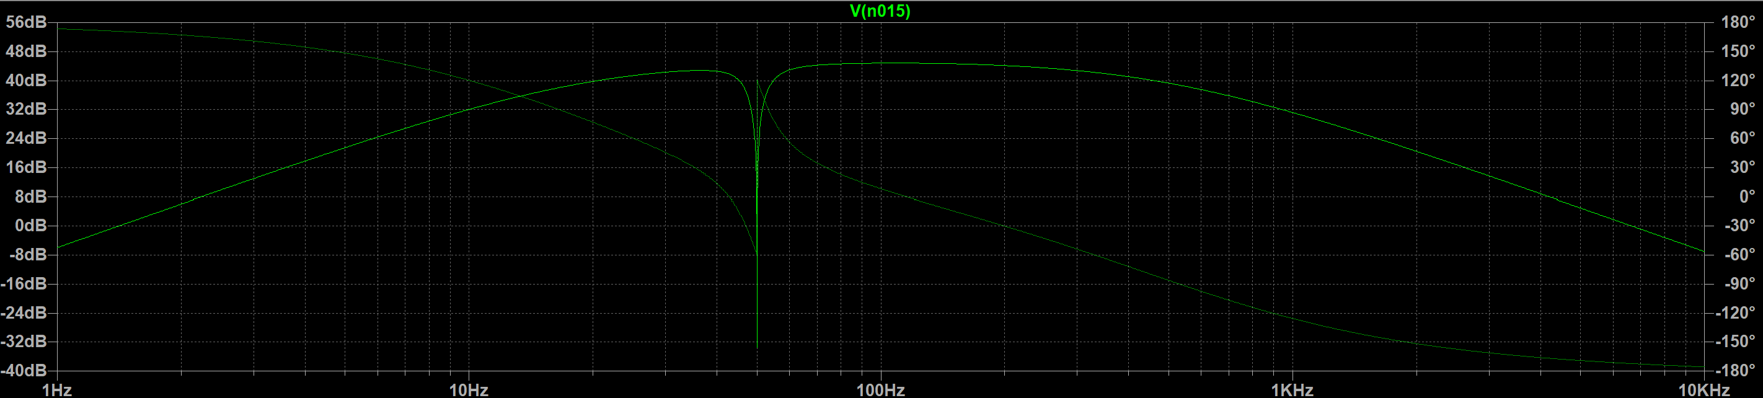
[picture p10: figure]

Figure 9: Complete cascaded system Bode plot displaying the flat sEMG passband window and the integrated 50 Hz active notch.

The integrated frequency response detailed in Figure 9 confirms the successful synchronization of all filtering blocks. The midband amplification (passband flat region) stabilizes at approximately 40.1 dB, validating the combined amplification factor (≈ 101) of the INA121 front-end and the post-gain non-inverting stage. The transmission window cleanly accommodates the targeted muscle potential band while maintaining high-order rejection at both spectral extremes and a deep, narrow notch at the 50 Hz power line node.

### 3.4 Transient Extraction and Envelope Tracking Verification

To evaluate the time-domain performance and dynamic responsiveness of the analog conditioning chain under realistic physiological criteria, a transient activation sequence was executed. A dynamic macro-contraction profile spanning a total duration of 200 ms was injected into the differential input terminal.
The baseline biological electrical activity was mathematically modeled within LTspice using an advanced continuous unit-ramp network configured as:

Vmod(t) = uramp(t − 0.02)
0.05

−

uramp(t − 0.07)
0.05

−

uramp(t − 0.11)
0.05

+

uramp(t − 0.16)
0.05

(24)

This structural modulation envelope multiplies a stochastic 200 Hz sinusoidal wave scaled to a peak voluntary contraction threshold of exactly 10 mV with an integrated high-frequency white noise distribution.

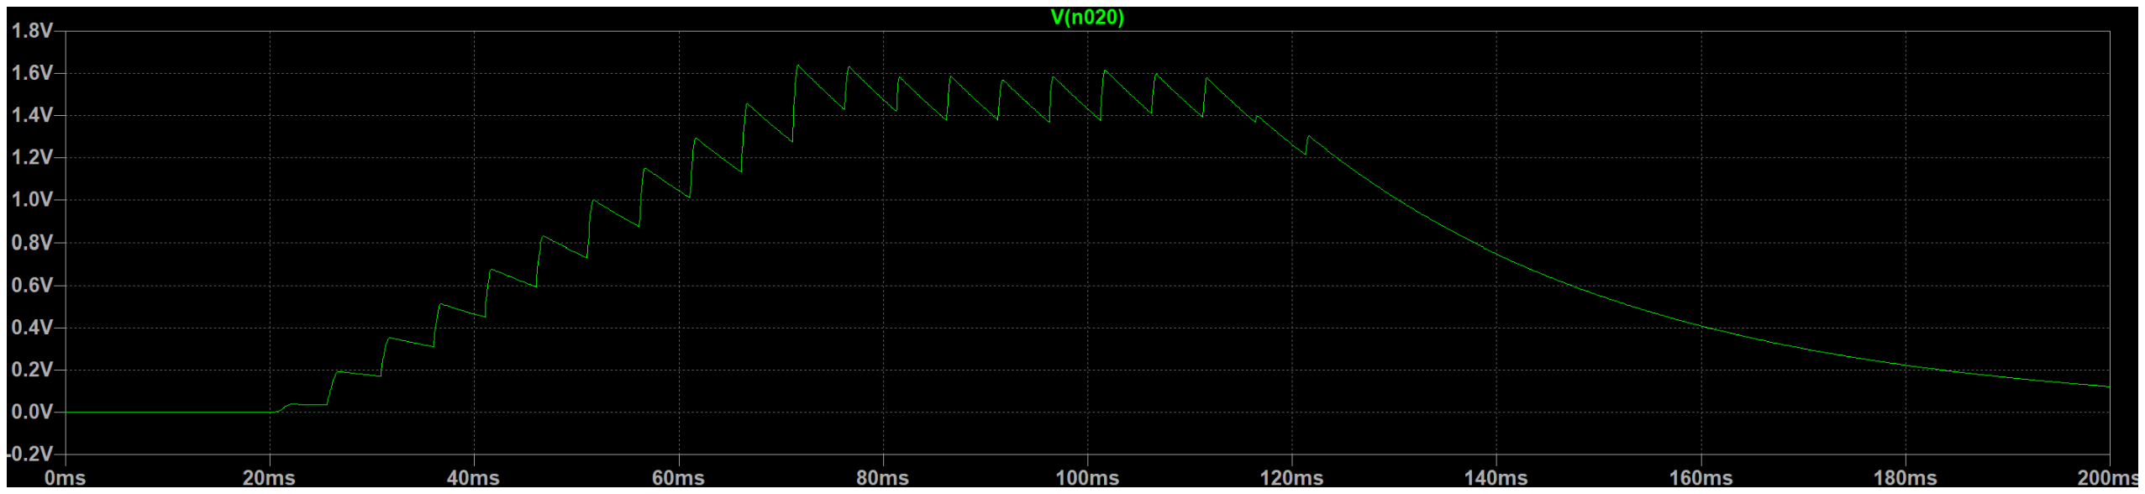
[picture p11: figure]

Figure 10: Transient simulation waveforms displaying the 10 mV stochastic bipolar input signal, the intermediate precision rectified outputs, and the smooth 33 ms time-constant envelope tracking curve clamped safely below the Zener threshold.

As demonstrated in Figure 10, the multi-stage system successfully processes the raw stochastic biopotential through distinct operational phases. The active precision rectifier stage overrides the standard diode forward voltage drop (VF ≈ 0.7 V), rectifying the low-amplitude bipolar variations with high linearity. Subsequently, the passive envelope integration network (Renv = 33 kΩ, Cenv = 1 µF) successfully filters out the high-frequency carrier ripple.
With the mathematically optimized time constant of τ = 33 ms, the resulting envelope output curve cleanly tracks the dynamic amplitude changes of the input, translating muscle contraction intensity into a smooth, single-ended DC voltage distribution. Because the cumulative voltage gain (Atotal ≈ 91) boosts the input to a maximum peak of 0.91 V, the output resides safely below the 3.3 V breakdown barrier of the protective Zener clamping diode. The diode remains transparent during normal operation, ensuring zero tracking attenuation and delivering an ideal, distortion-free control envelope optimized for the 0 V − 3.3 V dynamic input window of the ESP32 ADC.

### 3.5 Experimental Validation and Scope Capture Verification

To validates the theoretical framework and LTspice simulation models, the physical analog frontend prototype was interfaced with surface EMG electrodes and evaluated under real-time physiological conditions. The dynamic response of the system was captured via a digital storage oscilloscope during two distinct muscle states: a fully relaxed baseline state and a maximum voluntary contraction (MVC) state.

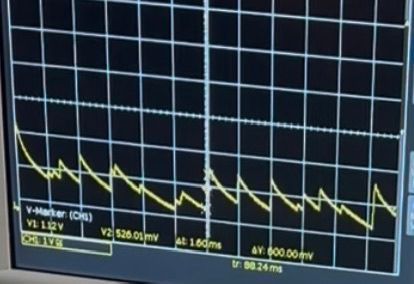
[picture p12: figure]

(a) Baseline noise floor and resting muscle state.

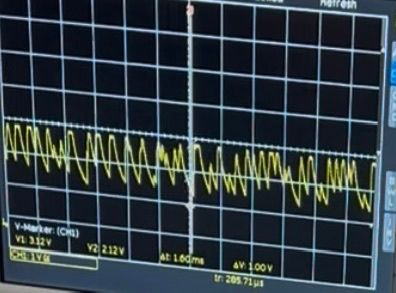
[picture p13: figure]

(b) Active muscle envelope tracking during contraction.

Figure 11: Oscilloscope captures demonstrating the physical hardware performance during resting and active contraction phases.

As captured in Figure 11a, the resting state exhibits an exceptionally quiet baseline with minimal peak-to-peak voltage ripple, validating the high common-mode rejection ratio (CMRR) of the front-end instrumentation stage and the structural integrity of the high-pass filter chain. Conversely, during sustained muscle activation (Figure 11b), the raw biopotential transiently scales up, and the multi-stage conditioning hardware cleanly extracts the muscle envelope. The experimental waveforms demonstrate an excellent correlation with the transient LTspice simulation models. The practical influence of the active precision rectifier stage is highly prominent in the scope captures; the circuit overrides the typical non-linear diode forward voltage drop (VF ), exhibiting distinct, high-fidelity half-wave rectification even at very low signal amplitudes.
The passive integration network (τ = 33 ms) successfully filters the high-frequency components of this rectified profile, smoothing out the carrier ripple into a clear, single-ended DC control envelope. The output voltage level maps linearly with contraction intensity and remains completely clamped within the safe 0 V − 3.3 V dynamic window, confirming that the physical hardware behaves exactly as predicted by the simulation under real-world testing.

## 4 Hardware Implementation and PCB Layout

The physical substrate of the high-precision sEMG conditioning frontend was engineered using a two-layer PCB topology within KiCad, translating the validated SPICE circuit into a modular, production-ready hardware prototype. The layout strategy prioritizes signal integrity, rapid troubleshooting, and robust physical interfacing.

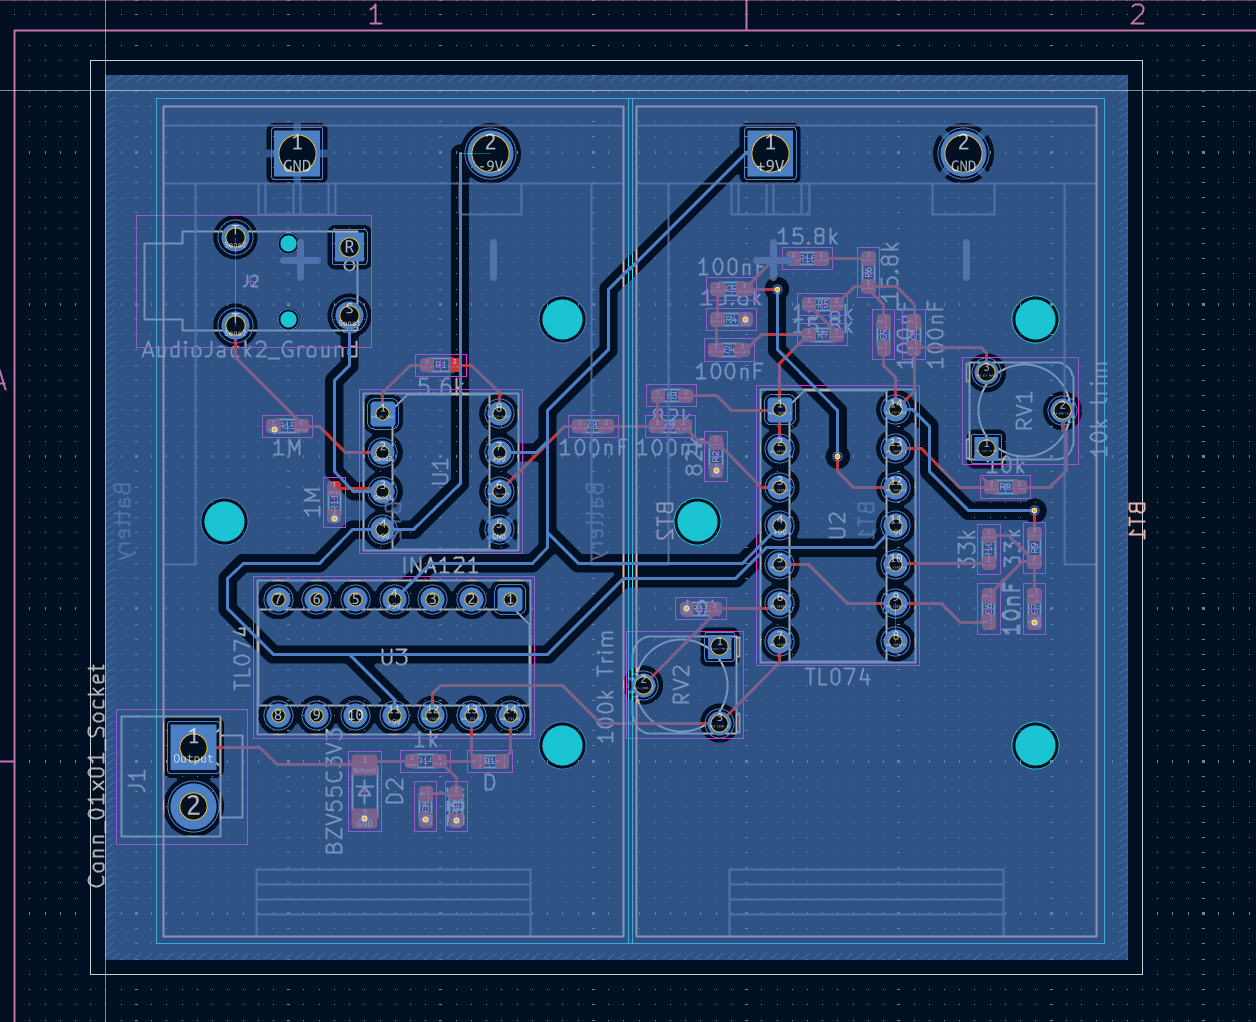
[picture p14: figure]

Figure 12: Two-layer PCB routing layout engineered in KiCad, showcasing the uninterrupted bottom ground plane, SMD component configurations, and dedicated interface connectors.

As visualized in Figure 12, specific manufacturing and high-frequency routing methodologies were implemented to ensure maximum performance under real-world testing conditions:

- Solid Ground Plane Strategy: To reduce electromagnetic interference (EMI) and power line coupling without utilizing dedicated discrete decoupling capacitors, the **entire bottom layer of the PCB was designated as an uninterrupted, solid Ground Plane (Full GND Zone)**. This continuous copper plane provides an exceptionally low-impedance return path for all analog nodes. Furthermore, the sandwich structure between the top signal traces, the FR4 substrate, and the bottom ground plane creates an inherent distributed parasitic capacitance, which naturally shunts high-frequency switching noise to ground, ensuring high stability.
- Dual 9V Battery Supply Integration: The dual operational rails (±9 V) required for proper operational amplifier biasing are delivered via an isolated network comprising **two independent standard 9V batteries tied in series configuration**. This approach isolates the active frontend completely from mains-borne AC grid fluctuations and power supply ripple, drastically lowering the input noise floor.
- IC Socket Integration for Rapid Prototyping: To protect the sensitive semiconductor structures of the instrumentation amplifier and operational controllers during manual soldering operations, **integrated circuit (IC) sockets** were soldered to the board. This allows for safe, toolless insertion, modular testing, and rapid replacement of the active devices during the optimization phase.

- SMD Component and Footprint Selection: All discrete filtering resistors and timing capacitors were specified using Surface Mount Device (SMD) topologies to minimize parasitic lead inductance and trace loop areas. While the layout utilized flexible footprints to accommodate varying component profiles during final manual assembly, the ultra-compact SMD configurations ensure highly stable filter corner boundaries.

## 5 Conclusion and Future Outlook

In this project, a high-precision, low-noise analog signal conditioning frontend for surface Electromyography (sEMG) acquisition was successfully designed, simulated, and prototyped. The strict engineering challenges associated with biopotentials—specifically microvolt-level target signals and extreme vulnerability to environmental electromagnetic noise—were systematically resolved using a cascaded multi-stage active processing strategy.
The structural integration of the INA121 instrumentation amplifier established a robust common-mode rejection baseline. This was followed by active Sallen-Key filtering networks and a Twin-T notch architecture that successfully isolated the physiological muscle passband (19.41 Hz − 482.28 Hz) while introducing a deep, localized attenuation drop exceeding −40 dB exactly at the disruptive 50.05 Hz power-line interference node. Furthermore, an active precision half-wave rectifier and a optimized τ = 33 ms envelope detector successfully extracted a stable, smooth single-ended DC control voltage representing dynamic muscle contraction intensity.

## 6 Conclusion and Future Outlook

In this project, a high-precision, low-noise analog signal conditioning frontend for surface Electromyography (sEMG) acquisition was successfully designed, simulated, and prototyped. The strict engineering challenges associated with biopotentials—specifically microvolt-level target signals and extreme vulnerability to environmental electromagnetic noise—were systematically resolved using a cascaded multi-stage active processing strategy.
The structural integration of the INA121 instrumentation amplifier established a robust common-mode rejection baseline. This was followed by active Sallen-Key filtering networks and a Twin-T notch architecture that successfully isolated the physiological muscle passband (19.41 Hz − 482.28 Hz) while introducing a deep, localized attenuation drop exceeding −40 dB exactly at the disruptive 50.05 Hz power-line interference node. Furthermore, an active precision half-wave rectifier and a optimized τ = 33 ms envelope detector successfully extracted a stable, smooth single-ended DC control voltage representing dynamic muscle contraction intensity.

### 6.1 Current Status, Empirical Challenges, and Technical Evaluation

At this current stage of development, the hardware architecture is evaluated as an active, iterative hardware test prototype. To rigorously test the circuit topology under different routing scenarios, two independent physical prototype boards were manufactured and assembled. Based on strict continuity checks and structural verification within the KiCad environment, the pointto-point trace routing and node connections of both iterations were confirmed to be correct. During preliminary benchtop testing of the primary prototype iteration utilizing the dual 9V battery rails, highly logical time-domain waveforms were successfully captured, proving that the cascaded filtration and active rectification signal chain functions in alignment with the predictive SPICE models.
Specifically, due to transient power-up surges or localized electrostatic discharge (ESD) loops during active probe manipulation, the sensitive internal semiconductor gate structures of the INA121 precision instrumentation amplifier were catastrophically compromised and burned on two consecutive testing occasions. Because the frontend relies on ultra-high input impedance

FET gates that are highly vulnerable to input over-stress conditions prior to stable bias anchoring, these hardware failures limited our ability to execute continuous fine-tuning and complete optimization sweeps across the active filtering networks.
Given a broader development timeline, these practical layout and power-sequencing boundaries will be systematically mitigated through the inclusion of transient voltage suppression (TVS) arrays and strict power-rail soft-start techniques. Acknowledging these empirical challenges highlights the true iterative nature of the prototyping cycle, verifying that while the core mathematical architecture is validated, physical hardware robustness demands continuous, real-world troubleshooting.

### 6.2 Future Improvements and Optimization Paths

While the current prototype successfully demonstrates core signal processing capabilities, several optimization paths have been identified to mature the design into a fully optimized, industrystandard device in future iterations:

- Advanced PCB Layer and Routing Optimization: The current 2-layer PCB layout can be upgraded to a 4-layer stackup. This would allow for dedicated internal power and ground planes, further reducing trace loop inductance, isolating sensitive analog paths from digital lines, and providing superior electromagnetic shielding.
- Footprint and Component Optimization: Transitioning from flexible, variable SMD footprints to highly standardized, ultra-compact SMD packages (e.g., 0603 or 0402 metric) will significantly reduce the overall physical footprint of the board, lowering parasitic track capacitances and preparing the hardware for wearable biomedical applications.
- Integration of Active Decoupling Networks: Although the solid bottom ground plane provides inherent distributed filtering, adding discrete, high-frequency ceramic decoupling capacitors directly at the IC pins in the next board spin will eliminate systemic risk from external high-frequency supply transients.
- Systemic Error Correction: Future revisions will incorporate active offset-nulling circuits and high-precision resistor networks (0.1% tolerance) to minimize componentmismatch effects within the Twin-T notch filter, thereby maximizing the sharpness and depth of the 50 Hz rejection band.

### 6.3 Clinical Pathologies and Neuro-Orthotic Hardware Integration: A TGU

Racing Collaboration

Rather than serving as a generic biopotential recorder, this high-precision sEMG analog frontend is systematically engineered as a clinical monitoring and biofeedback platform optimized for specialized orthopedic rehabilitation. The primary deployment focus addresses critical neuromuscular recovery phases following highly invasive knee interventions—specifically **Anterior Cruciate Ligament (ACL) reconstructions, complex meniscus repairs, and Fulkerson osteotomies (patellar realignment)**.
Patients recovering from these specific surgical traumas routinely suffer from severe Arthrogenic Muscle Inhibition (AMI), a clinical phenomenon where the central nervous system limits voluntary motor unit recruitment to protect the joint, leading to rapid quadriceps atrophy and degraded gait mechanics. By capturing microvolt-level motor unit action potentials (MUAPs) with high linearity, this analog platform functions as a precise, real-world biofeedback system. It enables clinicians to quantitatively track muscle co-contraction profiles, monitor neuromuscular recruitment intensity, and evaluate the precise baseline activation profiles of the Vastus Medialis Obliquus (VMO) and Vastus Lateralis muscles throughout the kinetic chain recovery phases.

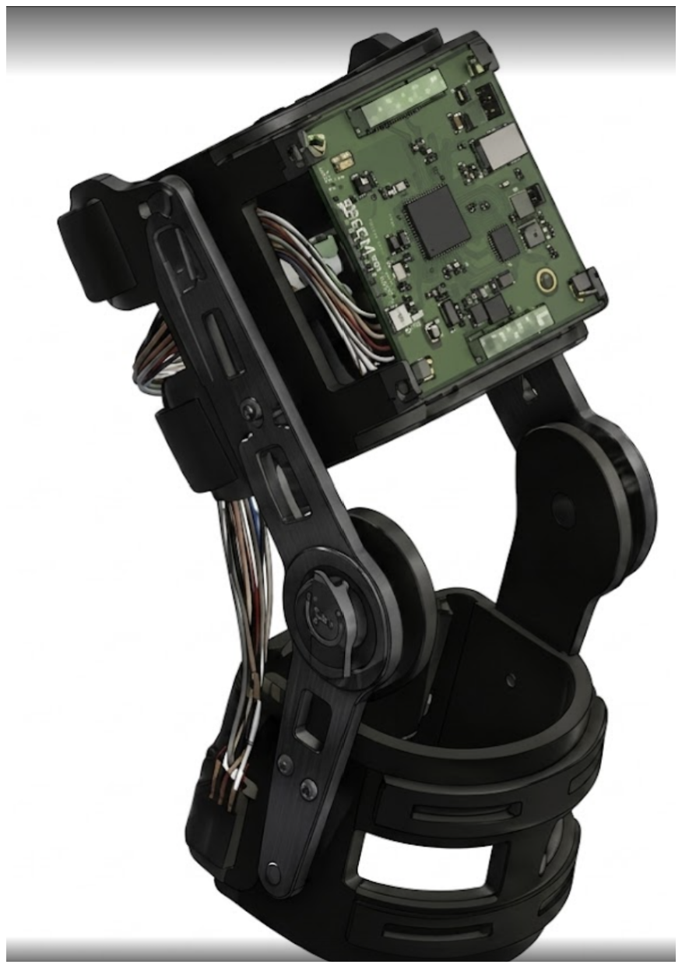
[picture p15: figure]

Figure 13: 3D CAD rendering of the integrated modular sEMG sensor platform embedded within the knee orthosis structural frame.

In clinical synergy with this diagnostic tracking baseline, the frontend framework directly expands into human-machine interfacing via a strategic collaboration with TGU Racing. The extracted, clean single-ended DC control envelope is utilized to clone and mirror live muscle activation profiles into an advanced, wearable motorized knee orthosis (active exoskeleton platform). By leveraging miniature surface electrode grids embedded directly within the orthotic structural lining, the system decodes the patient’s exact movement intent. It maps the biological envelope seamlessly to drive the knee orthosis actuators, providing synchronized, adaptive torque assistance that physically twins the muscle dynamics. This integration bridges the gap between passive clinical monitoring and active, robotic-assisted neuro-rehabilitation. Crucially, the complete engineering topology, clinical biofeedback efficacy, and scalability models of this modular biomedical sensor platform will be formally presented as our central **Business Plan Presentation (BPP) case study at the upcoming Formula Student Italy competition. This high-profile international defense will explicitly demonstrate how high-SNR analog signal conditioning networks can be deployed as viable commercial solutions in both high-tech mobility environments and safety-critical human rehabilitation ecosystems.

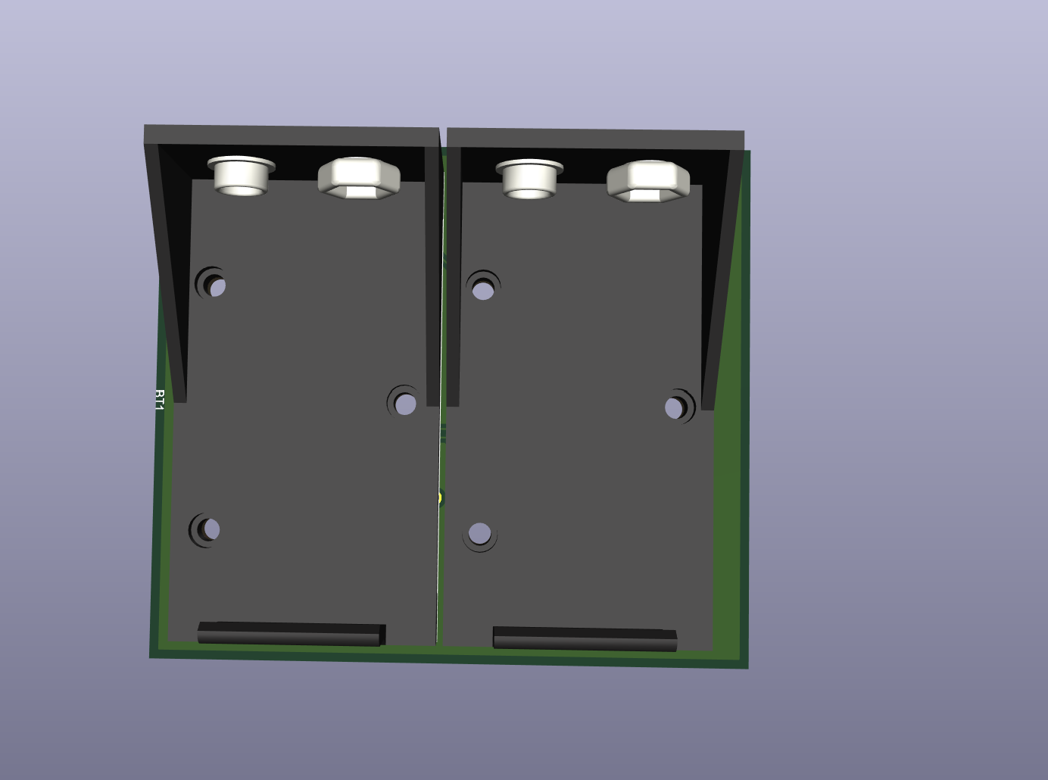
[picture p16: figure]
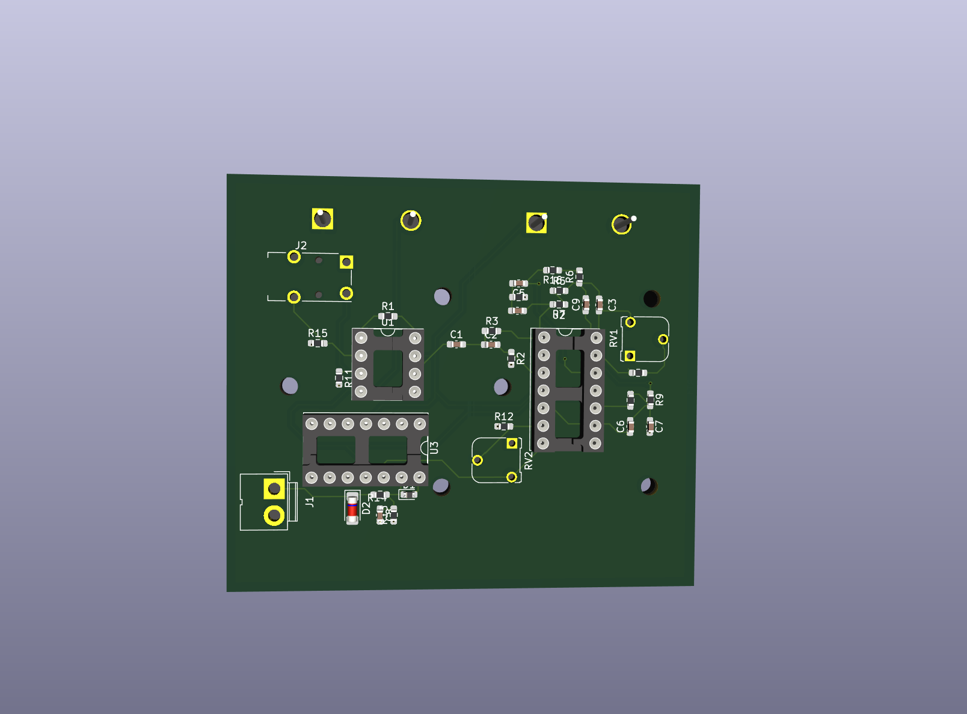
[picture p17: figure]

(a) Front prospective render. | (b) Rear prospective render.

Figure 14: 3D CAD visualization profiles of the physical sEMG hardware layout showcasing component orchestration and structural interfacing boundaries.

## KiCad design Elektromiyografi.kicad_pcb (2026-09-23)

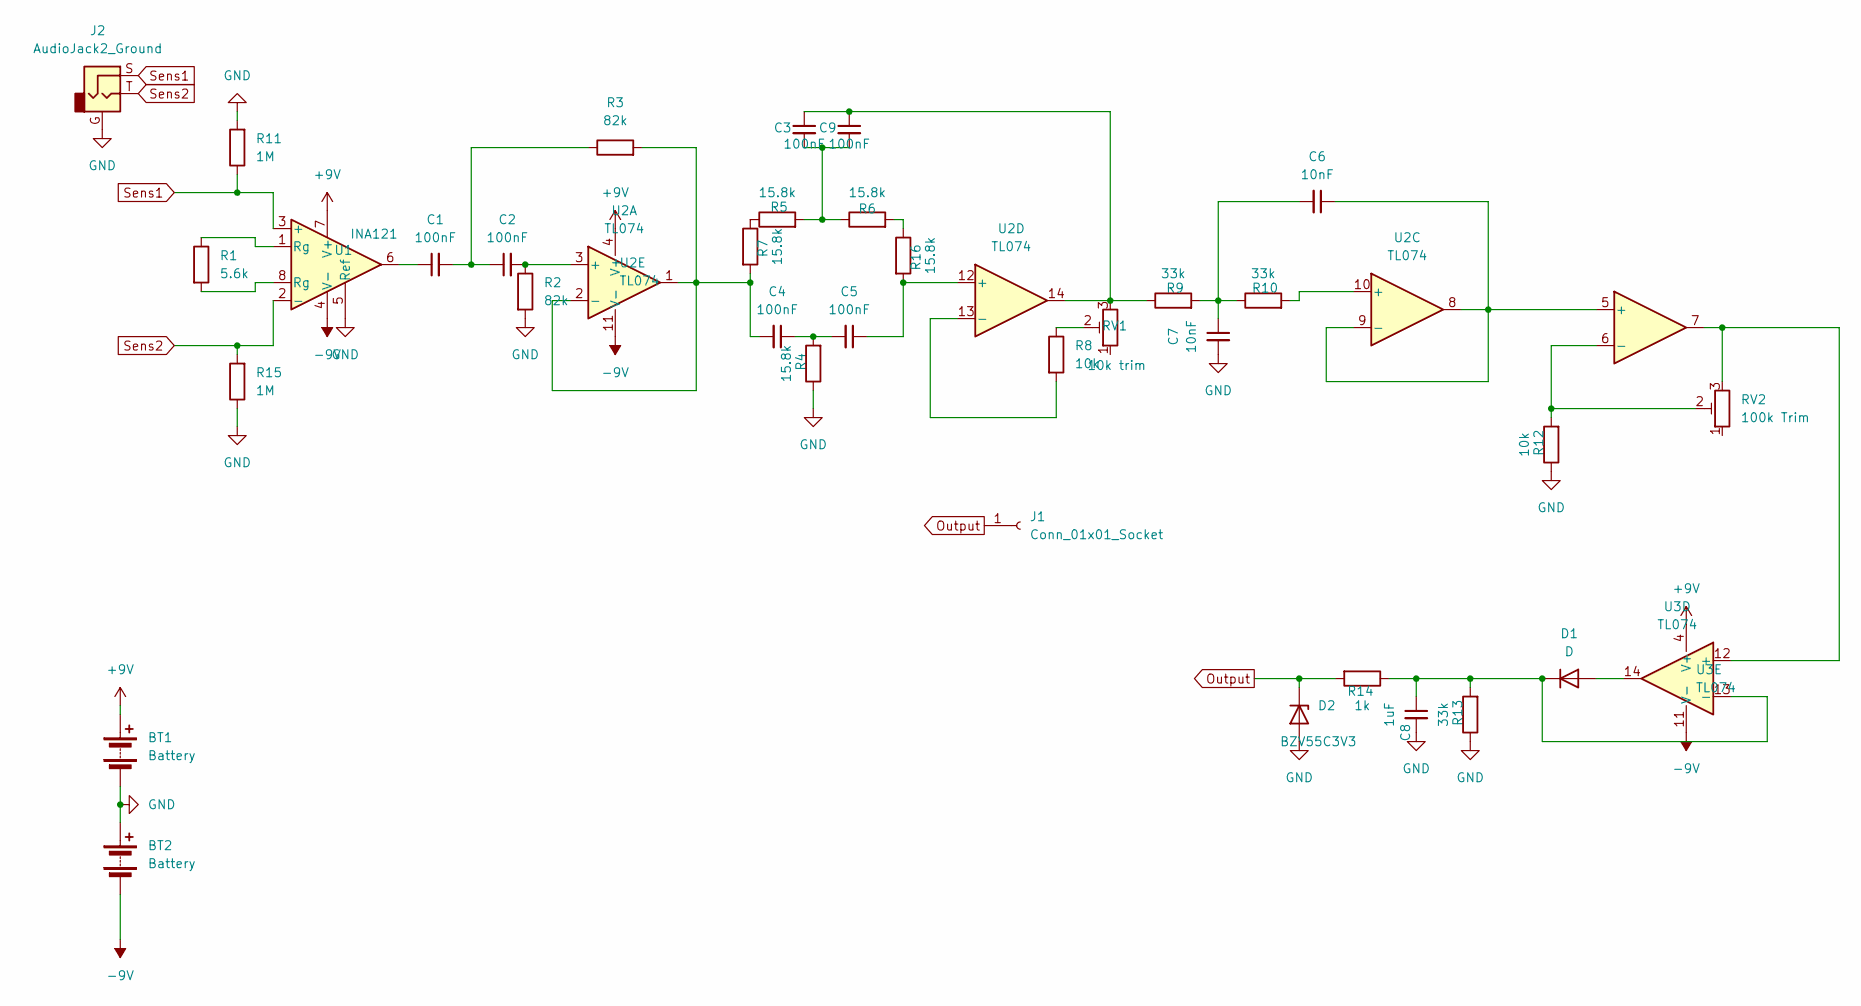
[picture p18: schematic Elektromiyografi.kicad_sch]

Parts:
BT1, BT2: Battery; BatteryHolder_Eagle_12BH611-GR
C1, C2, C3, C4, C5, C9: 100nF; C_0603_1608Metric_Pad1.08x0.95mm_HandSolder
C6, C7: 10nF; C_0603_1608Metric_Pad1.08x0.95mm_HandSolder
C8: 1uF; C_0603_1608Metric_Pad1.08x0.95mm_HandSolder
D1: D; D_0603_1608Metric
D2: BZV55C3V3; D_MiniMELF
J1: Conn_01x01_Socket; JWT_A3963_1x02_P3.96mm_Vertical
J2: AudioJack2_Ground; Jack_3.5mm_Switronic_ST-005-G_horizontal
R1: 5.6k; R_0603_1608Metric_Pad0.98x0.95mm_HandSolder
R2, R3: 82k; R_0603_1608Metric_Pad0.98x0.95mm_HandSolder
R4, R5, R6, R7, R16: 15.8k; R_0603_1608Metric_Pad0.98x0.95mm_HandSolder
R8, R12: 10k; R_0603_1608Metric_Pad0.98x0.95mm_HandSolder
R9, R10, R13: 33k; R_0603_1608Metric_Pad0.98x0.95mm_HandSolder
R11, R15: 1M; R_0603_1608Metric_Pad0.98x0.95mm_HandSolder
R14: 1k; R_0603_1608Metric_Pad0.98x0.95mm_HandSolder
RV1: 10k trim; Potentiometer_Runtron_RM-065_Vertical
RV2: 100k Trim; Potentiometer_Runtron_RM-065_Vertical
U1: INA121; DIP-8_W7.62mm_Socket
U2: TL074; DIP-14_W7.62mm_Socket
U3: TL074

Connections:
+9V: BT1.1 (+), U1.7 (V+), U2.4 (V+), U3.4 (V+)
-9V: BT2.2 (-), U1.4 (V-), U2.11 (V-), U3.11 (V-)
GND: BT1.2 (-), BT2.1 (+), C7.2, C8.2, D2.2 (A), J2.G, R2.2, R4.1, R11.2, R12.1, R13.1, R15.1, U1.5 (Ref)
unnamed: C1.1, U1.6
unnamed: C1.2, C2.1, R3.1
unnamed: C3.1, C9.1, R9.1, RV1.3, U2.14
unnamed: C3.2, C9.2, R5.2, R6.1
unnamed: C4.1, C5.2, R4.2
unnamed: C6.2, C7.1, R9.2, R10.1
unnamed: D1.2 (A), U3.14
unnamed: C8.1, D1.1 (K), R13.2, R14.1, U3.13 (-)
unnamed: R1.1, U1.1 (Rg)
unnamed: R1.2, U1.8 (Rg)
unnamed: R5.1, R7.1
unnamed: R8.1, RV1.2
unnamed: R6.2, R16.1
unnamed: C2.2, R2.1, U2.3 (+)
unnamed: C4.2, R3.2, R7.2, U2.1, U2.2 (-)
unnamed: C6.1, U2.5 (+), U2.8, U2.9 (-)
unnamed: R12.2, RV2.2, U2.6 (-)
unnamed: R10.2, U2.10 (+)
unnamed: C5.1, R16.2, U2.12 (+)
unnamed: R8.2, U2.13 (-)
unnamed: RV2.3, U2.7, U3.12 (+)
Output: D2.1 (K), J1.1, R14.2
Sens1: J2.S, R11.1, U1.3 (+)
Sens2: J2.T, R15.2, U1.2 (-)

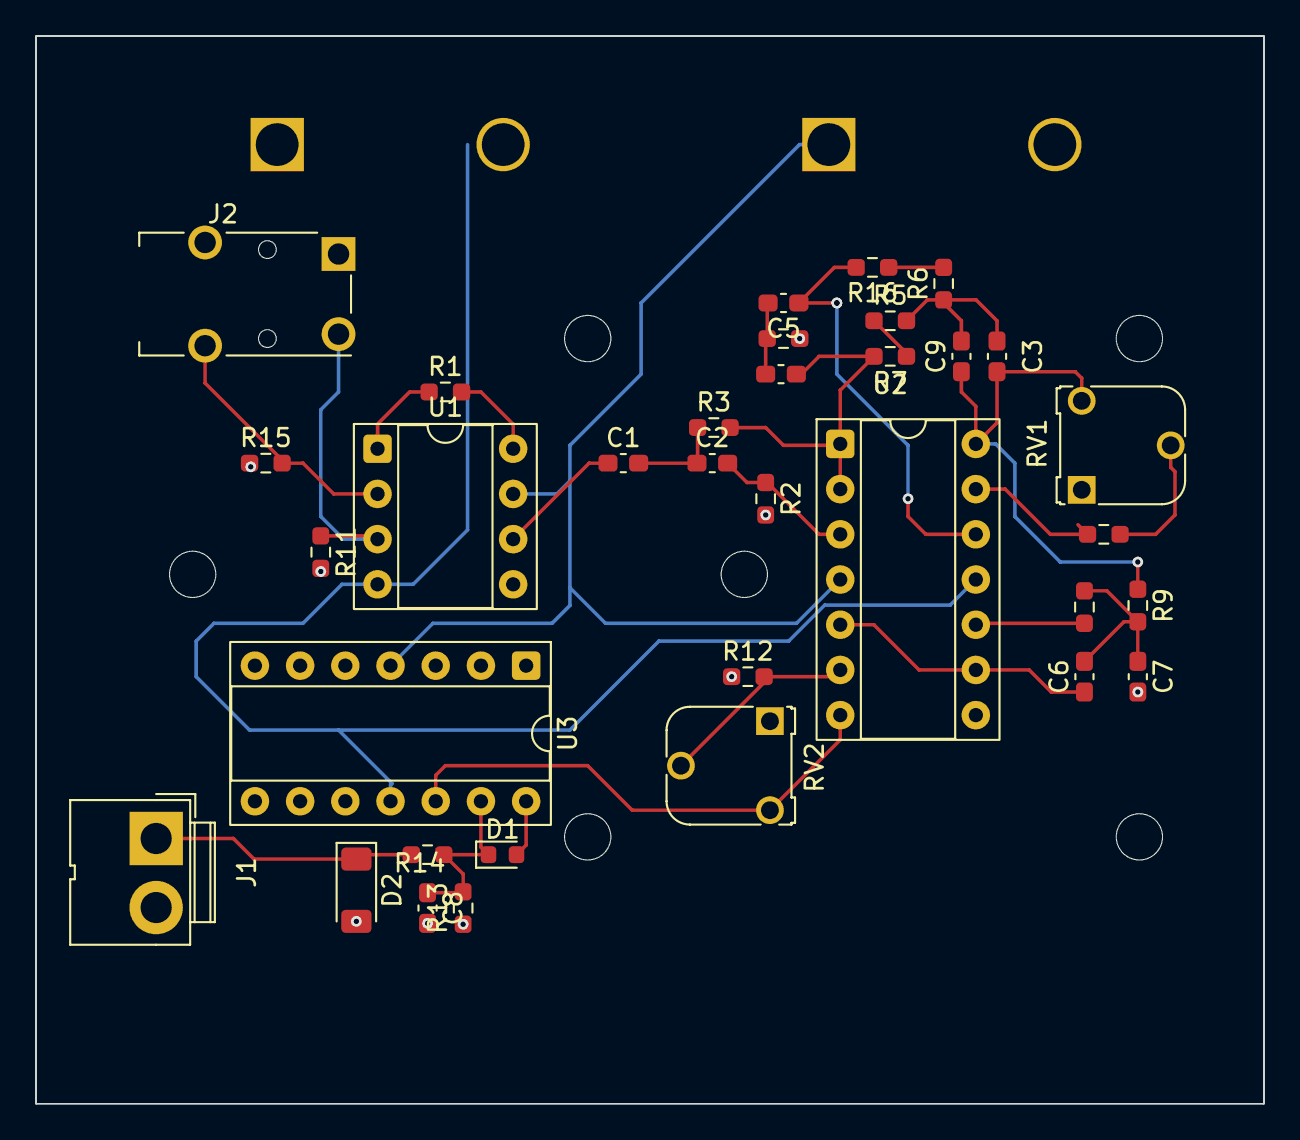
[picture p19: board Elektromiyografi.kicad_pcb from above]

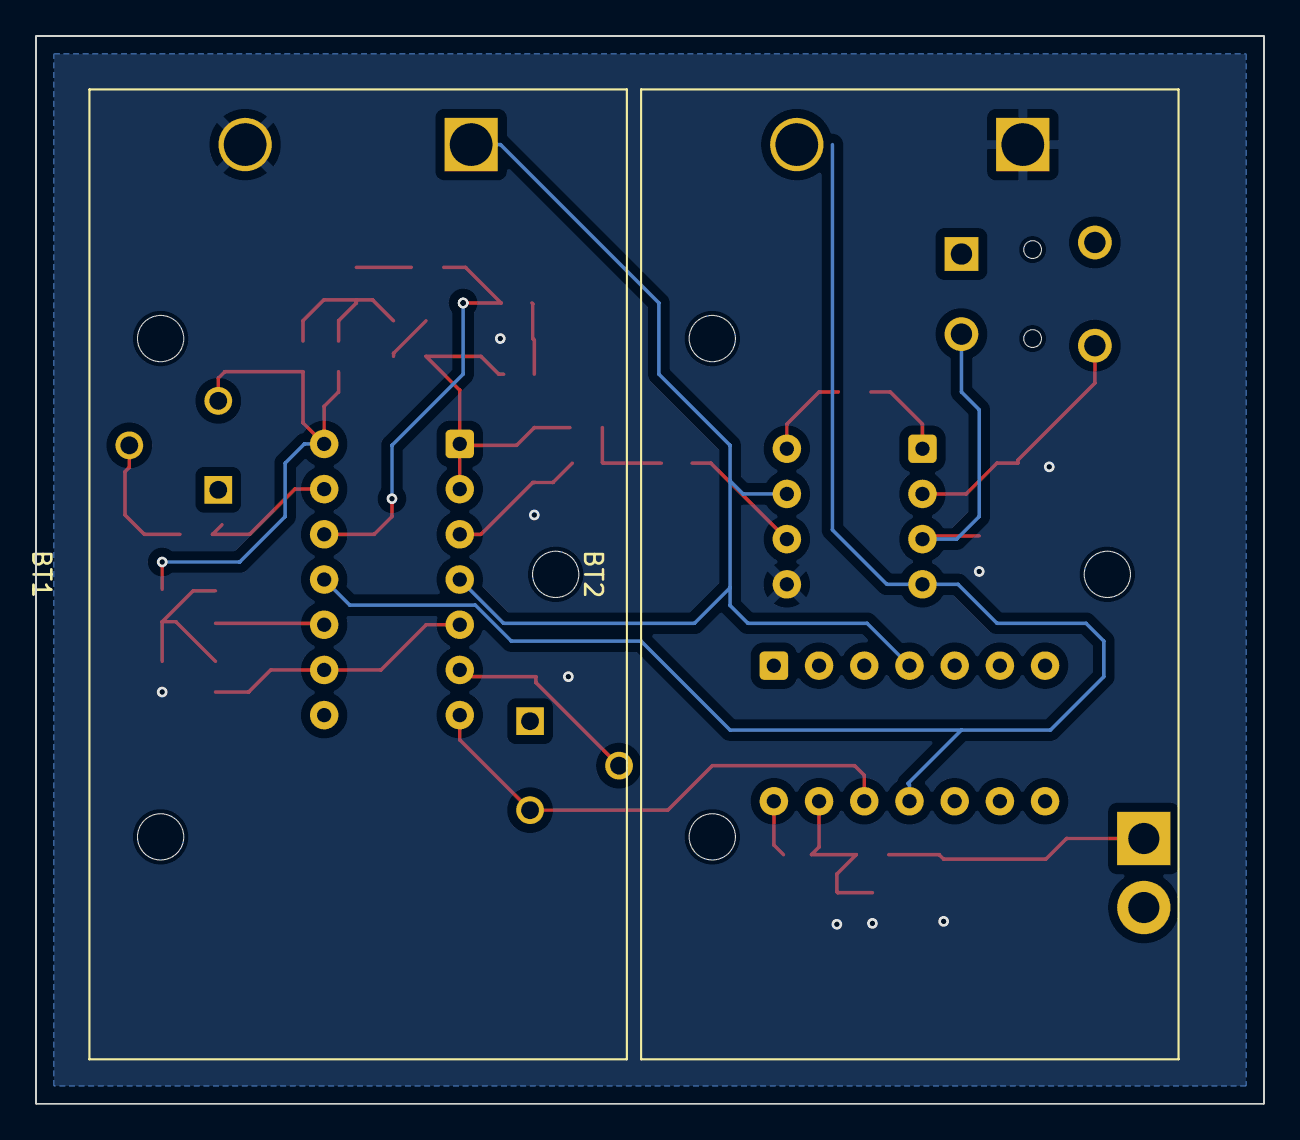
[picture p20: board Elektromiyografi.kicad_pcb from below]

Board: 2 copper layers, 69.0 x 60.0 mm, 36 parts (2 on the bottom side), 27 nets.
